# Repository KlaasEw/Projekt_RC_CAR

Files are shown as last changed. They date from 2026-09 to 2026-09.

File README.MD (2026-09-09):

# Projekt RC-Auto mit Notbremsassistent

## Inhaltsverzeichnis

1. [Projektziel](#1-projektziel)
2. [Systemüberblick](#2-systemüberblick)
3. [Hardware](#3-hardware)
4. [Notbremsassistent](#4-notbremsassistent)
5. [Telemetrie](#5-telemetrie)
6. [Software](#6-software)
7. [Stand, Grenzen, Ausblick](#7-stand-grenzen-ausblick)

---

## 1. Projektziel

Ziel des Projektes ist es, einen Notbremsassistenten für ein RC-Auto zu entwickeln. Daraus ergeben sich folgende Teilziele:

1. Das RC-Auto wird über eine Funkfernsteuerung gesteuert.
2. Das Fahrzeug soll über Abstandssensoren Hindernisse in der Umgebung erkennen.
3. Wird ein Hindernis erkannt, soll in die Ansteuerung des Motors eingegriffen werden, um das Fahrzeug zu verlangsamen und eine Kollision zu vermeiden.
4. Zur Überwachung des Fahrzeugs ist eine Übertragung der Telemetriedaten auf einen Mac zu realisieren. Die Daten sollen dort übersichtlich in einem Dashboard dargestellt werden.
5. Im Rahmen des Projektes ist zu evaluieren, welcher Mikrocontroller und welche Sensoren auf dem Fahrzeug für diesen Zweck genutzt werden können.

---

## 2. Systemüberblick

Das System umfasst das RC-Auto, einen zweiten ESP32 als Brücke zum Rechner und ein Dashboard auf dem Mac. Die Funkfernsteuerung bleibt die primäre Bedienung des Fahrzeugs. Der Mikrocontroller auf dem Auto wird zwischen den FlySky-Empfänger sowie ESC und Servo geschaltet. Die Steuerbefehle liegen am Empfänger als iBUS-Signal an. Der ESP32 wertet sie aus und gibt PWM-Signale an Motorregler und Lenkservo weiter.

Blockschaltbild des Gesamtsystems. Links Funkfernsteuerung und FlySky-Empfänger, in der Mitte der fahrzeugseitige ESP32 mit Anschlüssen zu ESC, Servo, RPLidar C1, MPU6050 und BME280. Rechts ESP-NOW zum zweiten ESP32,USB-Verbindung und Dashboard auf dem Mac. Steuerpfad und Telemetriepfad farblich tr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

Zur Erkennung von Hindernissen ist ein RPLidar C1 auf dem Fahrzeug montiert. Erkennt die Firmware ein Objekt in Fahrtrichtung, wird in die Gasvorgabe eingegriffen und das Fahrzeug verlangsamt. Über einen Schalter an der Fernsteuerung kann dieser Eingriff ein- und ausgeschaltet werden. Ein MPU6050 und ein BME280 erfassen zusätzlich Bewegungs- und Umgebungsdaten. Diese Werte dienen der Überwachung und werden mit der Telemetrie übertragen, sie fließen jedoch nicht in die Notbremslogik ein.

Zur Überwachung wird eine Telemetrieverbindung aufgebaut. Die am Fahrzeug anfallenden Daten werden per ESP-NOW an den zweiten ESP32 gesendet. Dieser ist per USB mit dem Mac verbunden und gibt die Pakete über die serielle Schnittstelle aus. Das Dashboard stellt die Telemetrie live dar.

---

## 3. Hardware

Nachfolgend wird die im Projekt verwendete Hardware beschrieben.

### 3.1 Fahrzeug und Antrieb

Foto des aufgebauten Fahrzeugs (Mali Racing BigHammer 2) von schräg vorn, sodass Antrieb, Empfängerbereich und aufgesetzte Sensorik erkennbar sind.

### 3.2 Stückliste

| Komponente | Typ |
| --- | --- |
| Auto | Mali Racing BigHammer 2 |
| Motor | QweenHobby 3670-2650KV |
| ESC | Hobbywing QuicRun WP 10BL120 G2 120A |
| Servo | B7018 9kg |
| Empfänger | FlySky FS-iA6B |
| Steuerung | FlySky FS-i6X |
| Akku | Conrad Energy 3S 25C (1800 mAh, 11,1 V) |
| Mikrocontroller | 2× ESP32 NodeMCU (Fahrzeug und Empfänger) |
| Umfeldsensor | Slamtec RPLidar C1 |
| IMU | MPU6050 (Beschleunigung und Gyroskop) |
| Umweltsensor | BME280 (Druck, Temperatur, Luftfeuchte) |
| Zubehör | Logic-Level-Shifter |
| | TS7805 (Spannungsregler 5 V) |

### 3.3 Schaltplan und Verdrahtung

Das Fahrzeug ist gemäß dem Schaltplan aufgebaut. Der Schaltplan wird in KiCad gezeichnet. Die folgende Belegung entspricht der Firmware und ist die Vorgabe für den Plan.

| Signal | ESP32 | Gegenstelle | Hinweis |
| --- | --- | --- | --- |
| Lidar RX | GPIO 16 | RPLidar TX | UART2, 460800 8N1 |
| Lidar TX | GPIO 17 | RPLidar RX | UART2 |
| iBUS RX | GPIO 34 | FlySky FS-iA6B iBUS | nur Eingang, 115200 8N1 |
| Motor PWM | GPIO 33 | ESC Signal | 50 Hz, 1000–2000 µs |
| Servo PWM | GPIO 32 | Lenkservo | 50 Hz, 1000–2000 µs |
| SDA | GPIO 21 | MPU6050, BME280 | I²C 400 kHz |
| SCL | GPIO 22 | MPU6050, BME280 | gemeinsam mit SDA |
| Lidar-Versorgung | TS7805 5 V  | RPLidar VCC | UART-Pegel 3,3 V, nicht 5 V |
| ESP32-Logik | 3,3 V | MPU, BME, UART | ESP32-Pins sind nicht 5-V-tolerant |
| Masse | GND | alle Baugruppen | gemeinsame Masse mit Akku/ESC |

Der RPLidar C1 braucht 5 V Versorgung, die UART-Leitungen sind 3,3 V. Ein Level-Shifter ist auf den Datenleitungen nur nötig, wenn 5-V-Pegel anliegen; gegenüber dem ESP32 dürfen keine 5 V auf RX/TX oder iBUS liegen. GPIO 34 kann ausschließlich lesen, deshalb liegt iBUS nur dort als Empfang. ESC und Servo werten das 3,3-V-PWM des ESP32 in der Regel direkt.

> **Abbildung 3 (Platzhalter):** KiCad-Schaltplan mit Spannungsversorgung (3S-Akku, TS7805), ESP32, iBUS, ESC, Servo, Lidar (UART) sowie I²C (MPU6050, BME280).

Foto der Verdrahtung im Fahrzeug, ergänzend zum Schaltplan.

### 3.4 Auswahl Mikrocontroller (ESP32 vs. Arduino Nano)

Zunächst wurde dieses Projekt mit einem Arduino Nano begonnen. Dieser stieß relativ schnell an seine Grenzen, da unter anderem drei native UARTs (iBUS, Lidar, Debug-Ausgabe) benötigt wurden. Daher wurde als Alternative der ESP32 getestet. Dieser verfügt zudem über die Funktechnik ESP-NOW, die für die Übertragung der Telemetriedaten sehr hilfreich war. Dadurch konnte auf den Einsatz eines zusätzlichen Funkmoduls verzichtet werden. Aus diesen Gründen wurde der Arduino Nano durch den ESP32 ersetzt.

| Kriterium | Arduino Nano | ESP32 |
| --- | --- | --- |
| Native UARTs | 1 | 3 (iBUS, Lidar, Debug-Ausgabe) |
| Funk (ESP-NOW) | nicht vorhanden | integriert |
| Zusätzliches Funkmodul | erforderlich | nicht erforderlich |

### 3.5 Auswahl Abstandssensor (RPLidar C1 vs. VL53L0X)

Im Laufe des Projektes wurde zunächst eine Kombination aus drei VL53L0X-Abstandssensoren getestet, da diese aus wirtschaftlichen Gründen zu bevorzugen war. Dabei wurden drei dieser Sensoren an der Front des Fahrzeugs über ein 3D-Druckteil montiert. Ein Sensor war direkt nach vorne ausgerichtet, die beiden anderen mit je 15° Neigung nach rechts und links. Im Rahmen der Evaluation wurde jedoch festgestellt, dass die Reichweite, in der Objekte sicher erkannt werden, maximal 1 m beträgt. Für die Geschwindigkeit, mit der sich das Fahrzeug bewegt, ist dieser Abstand deutlich zu gering.

Foto der drei VL53L0X-Sensoren am 3D-Druckteil, Frontansicht mit erkennbarer 15°-Neigung nach links und rechts.

Als Alternative wurde ein RPLidar C1 evaluiert. Der Sensor erstellt einen 360°-Scan der Umgebung mit einer Messreichweite von maximal 12 m. Die Datenmenge, die dieser Sensor liefert, ist für einen Mikrocontroller sehr hoch, daher werden nur drei Frontsektoren (links 315–345°, Mitte 345–15°, rechts 15–45°) genutzt.

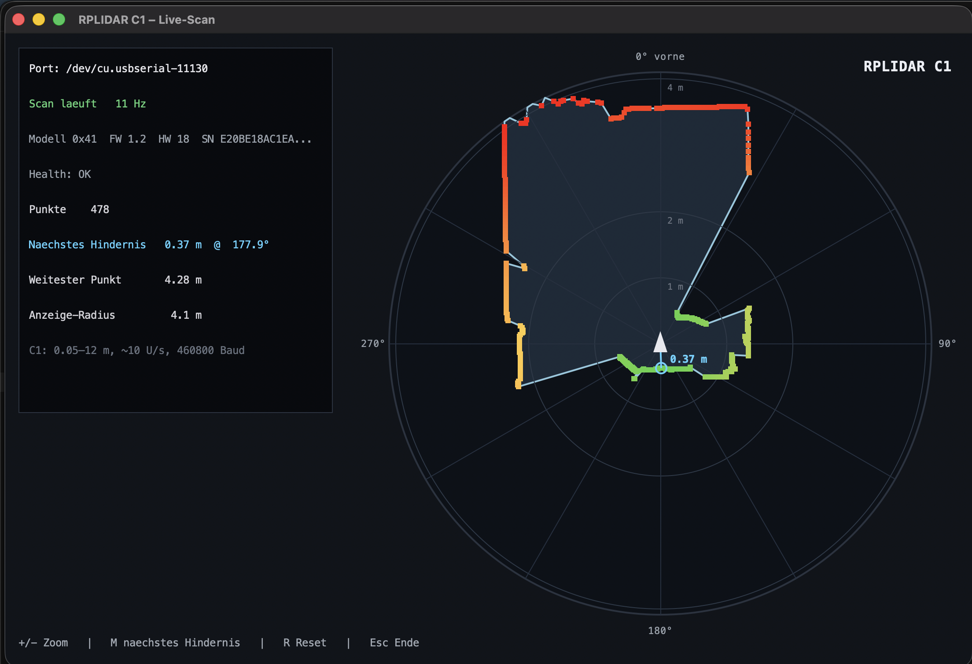
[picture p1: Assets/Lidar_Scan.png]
360° Scan des RP Lidar mir max. 12m Reichweite.


Aufgrund der gesammelten Daten wurde der Einsatz des RPLidar C1 beschlossen.

---

## 4. Notbremsassistent

Der Notbremsassistent sitzt in der Firmware des fahrzeugseitigen ESP32. Die Funkfernsteuerung bleibt die primäre Vorgabe. Der Assistent begrenzt lediglich die Gaswerte, die an den ESC weitergegeben werden. Die Lenkung wird unverändert durchgereicht.

Über einen Schalter an der Fernsteuerung (iBUS-Kanal 5) kann zwischen zwei Betriebsarten gewechselt werden. Ist der Assistent ausgeschaltet, werden die Empfängerwerte unverändert an ESC und Servo gegeben. Ist er eingeschaltet, wird die Gasvorgabe anhand der Lidar-Daten begrenzt.

Der RPLidar C1 liefert einen 360°-Scan. Für die Assistenz werden nur drei Frontsektoren ausgewertet (links 315–345°, Mitte 345–15°, rechts 15–45°). Je Sektor zählt die kleinste gültige Distanz in Millimetern. Daraus entsteht eine Gefahrenstufe. Welche Stufe tatsächlich greift, hängt von der Lenkung ab: Innerhalb einer Totzone von ±15° gilt der mittlere Sektor, außerhalb der Totzone der Sektor in Lenkrichtung.

Draufsicht der drei Frontsektoren und Zuordnung zur Lenkung. Cyan markiert den wirksamen Sektor (Totzone ±15°). Die Füllfarben im linken Beispiel entsprechen den Gefahrenstufen.

| Stufe | Bedeutung | Abstand | Begrenzung der Gasvorgabe |
| ----- | --- | --- | --- |
| 0 | frei | größer als 5000 mm  | ±60 |
| 1 | Hinweis | 3000–5000 mm | ±40 |
| 2 | Warnung | 1000–3000 mm | ±20 |
| 3 | Stopp | kleiner als 1000 mm | +10 / −15 |

Stufenkennlinie Abstand gegen Gasvorgabe

Die Gasvorgabe liegt im Bereich −100 bis 100. Auch bei freier Strecke bleibt eine Obergrenze von ±60 bestehen, solange der Assistent eingeschaltet ist. Stufe 3 ist kein vollständiger Halt: Es verbleibt ein geringer Vorwärts- und Rückwärtsanteil, damit das Fahrzeug nicht unkontrolliert stehen bleibt und weiterhin rangiert werden kann. Die Abstandsschwellen sind ein erster Arbeitspunkt und können später an das Fahrverhalten angepasst werden.

Fällt der Lidar aus oder liefert keinen gültigen Scan, wird die Gasvorgabe vorsorglich auf +15 / −20 begrenzt. Bleibt das iBUS-Signal länger als 100 ms aus, gilt Failsafe: Das Gas wird auf 0 gesetzt, die letzte Lenkstellung bleibt erhalten.

---

## 5. Telemetrie

Ziel der Telemetrie ist es, den Zustand des Fahrzeugs auf dem Mac nachvollziehbar zu machen. Dazu gehören die Vorgabe der Fernsteuerung, die tatsächlich ausgegebenen Stellgrößen, die Lidar-Sektoren samt Gefahrenstufen sowie die Messwerte von MPU6050 und BME280.

Die Übertragung erfolgt in zwei Schritten. Auf dem Fahrzeug werden die Daten in einem fest gepackten Binärpaket (Version 1, 63 Byte) zusammengestellt und per ESP-NOW an den zweiten ESP32 gesendet. Dieser prüft Länge, Versionsnummer und ein festes Erkennungsbyte am Paketanfang. Gültige Pakete werden in eine CSV-Zeile mit dem Prefix `TEL` umgewandelt und über USB (115200 8N1) an den Mac ausgegeben. Das Dashboard stellt diese Zeilen live dar und kann sie aufzeichnen.

**Abbildung 9:** Datenfluss der Telemetrie vom Fahrzeug zum Dashboard.

```mermaid
flowchart TB
    src["Sensoren und iBUS"]
    pack["Binärpaket<br/>63 Byte, Magic 0xA5"]
    now["ESP-NOW"]
    chk["Prüfung Empfänger-ESP32<br/>Länge, Version, Magic"]
    csv["CSV-Zeile<br/>Prefix TEL"]
    usb["USB 115200 8N1"]
    dash["Dashboard"]

    src -->|"Messwerte und rx"| pack
    pack -->|"binär"| now
    now --> chk
    chk -->|"gültig"| csv
    csv --> usb
    usb --> dash
```

Es werden bewusst nicht alle Lidar-Punkte übertragen. Eine vollständige Punktewolke würde das ESP-NOW-Limit von 250 Byte überschreiten. Stattdessen gehen nur die drei Sektorminima und die zugehörigen Gefahrenstufen ins Paket. Die Felder `rx` beschreiben den Wunsch der Fernsteuerung, die Felder `cmd` das, was Motor und Servo wirklich erhalten. Dadurch sind Eingriffe des Assistenten im Dashboard erkennbar. Eine laufende Sequenznummer und die Fahrzeugzeit in Millisekunden erlauben es, Verluste und die zeitliche Abfolge zu erkennen.

Die Pakete werden etwa alle 20 ms erzeugt. Der Lidar liefert neue Sektorwerte nur mit seiner Umlaufzeit; dazwischen werden die letzten gültigen Distanzen gehalten. Ungültige Sensorwerte werden auf 0 gesetzt und über Flags gekennzeichnet, unter anderem für MPU, BME, Lidar, Failsafe und einen aktiven Eingriff des Assistenten. Die Akkuspannung ist im Datenformat vorgesehen, im aktuellen Stand aber noch nicht angebunden. Die genaue Feldliste des Pakets ist in [`Note.md`](Note.md) beschrieben.

---

## 6. Software

Die einzelnen zu entwickelnden Funktionen wurden im Rahmen von diversen Prototypen getestet und am Ende zu einem gemeinsamen Stand für Fahrzeug und Empfänger zusammengeführt. Die Prototypen liegen im Ordner `prototyps/` und behandeln unter anderem iBUS, ESP-NOW, den MPU6050 und die Lidar-Auswertung. Die integrierte Software gliedert sich in drei Teile.

### 6.1 Firmware Fahrzeug

Die Firmware des Fahrzeugs liegt im Ordner `firmware_RC_Car` und wird mit PlatformIO für den ESP32 im Arduino-Framework gebaut. Sie vereint die zuvor getrennt erprobten Funktionen in einem Programm: das Auslesen des iBUS-Signals, die Ansteuerung von ESC und Servo per PWM, die Auswertung des RPLidar C1, das Einlesen von MPU6050 und BME280 sowie das Versenden der Telemetrie per ESP-NOW.

Die Lidar-Auswertung läuft in einem eigenen FreeRTOS-Task (`lidarTask`), nicht in der Arduino-`loop()`. Der Task ist auf Kern 1 gepinnt. Beim ESP32 mit Arduino-Framework läuft `loop()` standardmäßig ebenfalls auf Kern 1; Kern 0 bedient den WLAN-/ESP-NOW-Stack. Hauptschleife und Lidar-Task teilen sich damit denselben Kern. Der Lidar-Task hat die höhere Priorität (3 gegenüber 1) und gibt mit `vTaskDelay` regelmäßig ab, damit iBUS, PWM und Telemetrie weiterlaufen. Eine echte Verteilung auf zwei Anwendungskerne wäre erst gegeben, wenn der Lidar-Task auf Kern 0 läge.

In der Hauptschleife wird etwa alle 20 ms das iBUS-Signal ausgewertet, die Assistenzlogik angewendet und ein Telemetriepaket erzeugt. Parallel dazu schreibt die Firmware dieselbe CSV-Zeile auf die serielle Debug-Schnittstelle. Die Logik des Notbremsassistenten ist in Kapitel 4 beschrieben.

Vereinfachtes Firmware-Schema. Hauptschleife und Lidar-Task; beide auf Kern 1, Kern 0 für WLAN/ESP-NOW.

### 6.2 Firmware Empfänger

Die Empfänger-Firmware liegt im Ordner `firmware_Reciver`. Sie enthält keine Fahrlogik. Ihre einzige Aufgabe ist es, ESP-NOW-Pakete entgegenzunehmen, auf Länge, Versionsnummer und Erkennungsbyte zu prüfen und gültige Datensätze als CSV-Zeile über USB auszugeben. Ungültige oder unvollständige Pakete werden verworfen. Dadurch bleibt der Mac von der binären Funkstrecke entkoppelt; das Dashboard spricht nur die serielle Schnittstelle an.

### 6.3 Dashboard

Das Dashboard ist eine Python-Anwendung auf Basis von PySide6 und liegt im Ordner `Dashboard`. Es liest die CSV-Zeilen vom Empfänger-ESP32 und stellt den Fahrzeugzustand live dar. Eine Draufsicht zeigt das Auto mit Lenkeinschlag und den drei Lidar-Sektoren in der Farbe der jeweiligen Gefahrenstufe. Daneben wird die Lage im Raum aus den IMU-Daten angenähert. Werte von Fernsteuerung und Assistent (`rx` gegenüber `cmd`) sowie Flags für Sensorausfall, Failsafe und Eingriffe erscheinen in einer Seitenleiste.

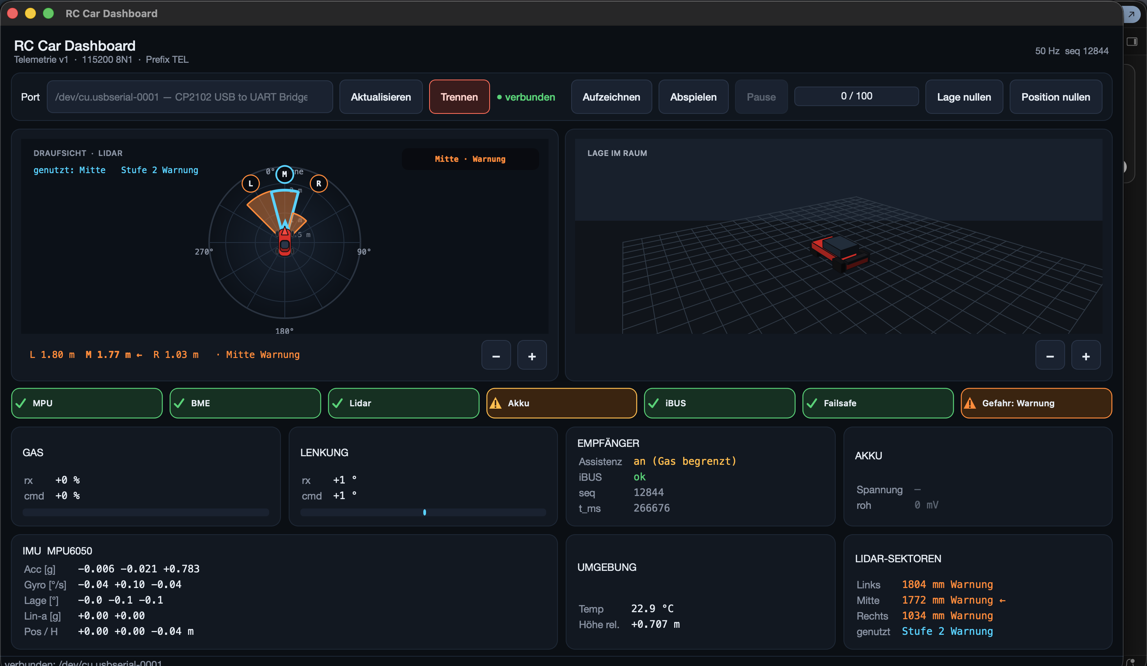
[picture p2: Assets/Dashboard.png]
Screenshot des Dashboards mit Draufsicht, Lage im Raum, Flags und Wertepanel ( / ).


Die Gefahrenstufen werden nicht neu berechnet, sondern unverändert aus dem Telemetriepaket übernommen. Zusätzlich können Live-Daten als CSV aufgezeichnet und später mit dem ursprünglichen Zeitverlauf abgespielt werden. Start und Bedienung sind in [`Dashboard/README.md`](Dashboard/README.md) beschrieben.

*Hinweis: Das Dashboard wurde vollständig über KI-Agenten erstellt.*

---

## 7. Stand, Grenzen, Ausblick

### 7.1 Stand

Die in Kapitel 1 genannten Teilziele sind im Wesentlichen umgesetzt. Das RC-Auto wird über die vorhandene Funkfernsteuerung gefahren. Der ESP32 sitzt zwischen Empfänger, ESC und Servo. Hindernisse werden mit dem RPLidar C1 in drei Frontsektoren erkannt, die Gasvorgabe kann stufenweise begrenzt und der Assistent an der Fernsteuerung ein- und ausgeschaltet werden. Mikrocontroller und Abstandssensor wurden evaluiert und begründet ausgewählt. Die Telemetrie erreicht den Mac, das Dashboard stellt die Werte live dar und kann Fahrten aufzeichnen.

### 7.2 Grenzen

Die entscheidende Grenze liegt in der Art des Eingriffs. Es wird nur die Gasvorgabe an den ESC verändert, nicht die tatsächliche Geschwindigkeit. Wird das Gas reduziert, bremst das Fahrzeug nicht unmittelbar ab, sondern rollt mit der vorhandenen kinetischen Energie weiter. Stufe 3 ist zudem kein Halt, und die Abstandsschwellen sind noch nicht an den realen Anhalteweg angepasst. Auf dieser Grundlage können Kollisionen derzeit nicht zuverlässig verhindert werden. Weitere Einschränkungen folgen daraus: Seitliche und hintere Bereiche des Lidar-Scans fließen nicht in die Assistenz ein, und die Akkuspannung ist im Datenformat vorgesehen, aber noch nicht gemessen.

### 7.3 Ausblick

Ein nächster Schritt wäre, die Fahrgeschwindigkeit zu messen und die Ansteuerung über einen PID-Regelkreis zu führen. Die Gefahrenstufe würde dann eine Zielgeschwindigkeit vorgeben, nicht nur eine Drosselung des Sticks. Erst damit ließe sich das Fahrzeug nach einer Reduktion wirklich verzögern, statt es ausrollen zu lassen. Ergänzend sollten die Abstandsschwellen am Fahrzeug kalibriert und die Akkuspannung in die Telemetrie übernommen werden.

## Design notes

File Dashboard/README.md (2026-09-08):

# RC Car Dashboard

Live-Telemetrie vom Empfänger-ESP32 über USB-Serial. Dunkles PySide6-Dashboard auf dem Mac: Draufsicht mit Lidar-Sektoren, Lage im Raum, Werte, Flag-Warnungen, CSV-Aufzeichnung und Wiedergabe.

Datenpfad: Auto-ESP → ESP-Now → Empfänger-ESP (`firmware_Reciver`) → USB 115200 8N1 → diese App. Protokoll laut `Note.md` (CSV-Zeilen mit Prefix `TEL`).

## Start

Python 3.9 oder neuer. Im Ordner `Dashboard/`:

```bash
python3 -m venv .venv
source .venv/bin/activate
python3 -m pip install -r requirements.txt
python3 main.py
```

## Verbinden

1. Empfänger-ESP32 per USB anschließen.
2. **PlatformIO-Serial-Monitor, Arduino-IDE und andere Programme schließen.** Der Port darf nur einmal geöffnet sein.
3. Im Dashboard den Port wählen (auf macOS `/dev/cu.…`, nicht `/dev/tty.…`) und **Verbinden**.
4. Baudrate ist fest **115200**. Debug-Zeilen ohne `TEL` werden ignoriert.

Ports aktualisieren, falls der Stick später eingesteckt wird.

## Bedienung

| Aktion | Wirkung |
| --- | --- |
| Verbinden / Trennen | Serial öffnen oder schließen |
| Aufzeichnen | Live-Pakete nach `recordings/tel_YYYYMMDD_HHMMSS.csv` |
| Abspielen | vorhandene CSV mit Original-Timing über `t_ms` |
| Pause | Wiedergabe anhalten |
| Lage nullen / `R` | Roll, Pitch, Yaw auf aktuelle Lage setzen |
| Position nullen / Leertaste | Spur und Position zurücksetzen |
| `X` / `Y` / `Z` | IMU-Achse invertieren |

## Anzeige

- **Draufsicht:** Auto von oben, Vorderräder nach `cmd_servo`. Weicht `rx_servo` ab, erscheint ein gelber Wunsch-Pfeil. Drei Lidar-Sektoren (Links 315–345°, Mitte 345–15°, Rechts 15–45°), Farbe nach Gefahrenstufe. Der von der Firmware genutzte Sektor (`rx_servo`-Deadzone 15°) ist cyan umrandet. `+` / `−` oder Mausrad zoomen.
- **Lage im Raum:** Komplementärfilter und Bewegung wie im Prototyp `Visualisierung_Car_Movment`. Ebenfalls `+` / `−` zum Zoomen.
- **Empfänger / Assistenz:** Fernsteuer-Schalter (iBUS-Kanal 5). *an* = Notbremsassistent aktiv (Lidar begrenzt Gas), *aus* = Werte werden durchgereicht.
- **Flags:** Warn-Dreieck, sobald der ungünstige Zustand vorliegt (MPU/BME/Lidar/Akku ungültig, Failsafe, iBUS stale). Gefahr folgt `danger_used`: Hinweis, Warnung oder Stop.
- **Werte:** `rx` vs. `cmd`, IMU, Temperatur, relative Höhe, Akkuspannung in Volt, Lidar mm.

Gefahrenstufen und `danger_used` kommen aus dem Paket, sie werden nicht neu berechnet.

## Aufnahmen

Ordner: `Dashboard/recordings/`. Erste Zeile ist der Header (`version,seq,t_ms,…`), danach dieselben Spalten wie die TEL-Zeile ohne Prefix. Live-`TEL,…`-Dumps können ebenfalls abgespielt werden. Nicht-TEL-Zeilen werden übersprungen.

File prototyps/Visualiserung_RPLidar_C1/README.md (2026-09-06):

# RPLIDAR C1 am Mac anschließen und visualisieren

Schritt-für-Schritt: Sensor per USB mit dem Mac verbinden und die Live-Punktewolke mit `visualize_lidar.py` anzeigen.

## Was du brauchst

- Slamtec **RPLIDAR C1**
- Das mitgelieferte **USB-Adapterboard** (meist CP210x, USB-A oder USB-C)
- Das kurze **XH2.54-Kabel** zwischen Lidar und Adapter (oft schon steckt)
- Einen freien USB-Anschluss am Mac (bei USB-C-Macs ggf. USB-A-Adapter)
- Python 3.9 oder neuer (`python3 --version`)

Der C1 braucht **5 V** und etwa **230 mA**. Ein normaler Mac-USB-Port reicht. Ungepowerte USB-Hubs lieber vermeiden.

Der Sensor ist Laserklasse 1. Trotzdem nicht direkt in das optische Fenster starren und das Fenster nicht abdecken.

---

## 1. Hardware verbinden

1. Lege den C1 auf eine **ebene, freie Fläche**. Der Markierungsstrich bzw. das Kabel am Sockel zeigt nach vorne (0° im Radar).
2. Stecke das **5-polige Kabel** vom Lidar in das USB-Adapterboard. Die Stecker sind verpolungssicher – nicht mit Gewalt umdrehen.
3. Verbinde das Adapterboard **per USB mit dem Mac**.
4. Der Motor darf sich jetzt noch nicht drehen. Die Laser-Einheit startet erst, wenn das Skript den Scan-Befehl schickt.

Pinbelegung nur zur Kontrolle (falls du ohne Adapterboard misst):

| Signal | Richtung | Bemerkung |
| --- | --- | --- |
| VCC | Versorgung | **5 V**, nicht 3,3 V |
| TX | Lidar → Mac | UART-Daten |
| RX | Mac → Lidar | UART-Befehle |
| GND | Masse | gemeinsam |

Logikpegel der UART-Leitungen: 3,3 V. Versorgung trotzdem 5 V.

---

## 2. Prüfen, ob macOS den Adapter sieht

Ab macOS 11 (Big Sur) ist der **CP210x-Treiber von Apple** schon dabei. Einen extra SiLabs-Treiber brauchst du in der Regel nicht. Einen alten, selbst installierten SiLabs-Treiber besser entfernen – der kann mit dem Apple-Treiber kollidieren.

Terminal öffnen und **alle** `cu`-Geräte listen (zsh-tauglich, ohne Glob-Fehler):

```bash
ls /dev/cu.*
```

Relevant sind Einträge mit `usbserial`, `SLAB`, `wchusbserial` oder `usbmodem`. Gezielter:

```bash
ls /dev/cu.* | grep -iE 'usbserial|SLAB|wchusb|usbmodem'
```

Erwartetes Ergebnis, zum Beispiel:

```text
/dev/cu.usbserial-1130
```

Nicht verwenden: `ls /dev/cu.usbserial* /dev/cu.SLAB* /dev/cu.wchusbserial*`. In zsh bricht der Befehl ab, sobald **eines** der Muster nichts findet – auch wenn der Lidar schon als `usbserial-…` da ist.

Wichtig: Immer **`/dev/cu.*`** verwenden, nicht `/dev/tty.*`. Die `tty.*`-Geräte warten auf ein Modem-Signal und blockieren.

Wenn nichts erscheint:

1. Anderen USB-Anschluss bzw. anderen Adapter versuchen.
2. Systemeinstellungen → Allgemein → Info → Systembericht → USB: nach „CP210x“, „Silicon Labs“ oder „USB-Serial“ suchen.
3. Kabel und Adapterboard prüfen. Manche Boards brauchen erst den Lidar-Stecker, bevor sie am USB enumerieren.
4. Falls wirklich kein Treiber da ist: [CP210x VCP Driver von Silicon Labs](https://www.silabs.com/developers/usb-to-uart-bridge-vcp-drivers).

---

## 3. Python-Umgebung einrichten

Im Projektordner:

```bash
cd prototyps/RPLidar_C1
python3 -m venv .venv
source .venv/bin/activate
python3 -m pip install -r requirements.txt
```

Es wird nur **pyserial** benötigt. Die Grafik läuft mit Tkinter, das bei der macOS-Python-Installation schon dabei ist.

Falls `tkinter` fehlt (selten, z. B. bei manchen Homebrew-Pythons):

```bash
brew install python-tk
```

---

## 4. Visualisierung starten

Zuerst die Ports listen:

```bash
python3 visualize_lidar.py --list
```

Der Eintrag mit `*` ist der vermutete C1 (CP210x / usbserial). Wenn gleichzeitig ein ESP32 steckt, den C1-Port explizit angeben.

Dann starten:

```bash
python3 visualize_lidar.py
```

oder fest:

```bash
python3 visualize_lidar.py --port /dev/cu.usbserial-1130
```

Nach 1–2 Sekunden sollte sich der Kopf drehen und im Fenster ein Radar erscheinen: Sensor in der Mitte, 0° oben = vorne.

### Bedienung

| Taste / Geste | Wirkung |
| --- | --- |
| `+` / `-` oder Mausrad | Zoom (Anzeige-Radius) |
| `M` | Nächstes Hindernis ein/aus |
| `R` | Zoom auf 8 m zurück |
| `Esc` oder `Q` | Beenden, Motor stoppen |

### Nützliche Optionen

```bash
python3 visualize_lidar.py --range 4      # Innenraum, 4 m Radius
python3 visualize_lidar.py --baud 460800  # Standard des C1, nur ändern wenn nötig
```

---

## 5. Wenn etwas nicht klappt

**Fenster bleibt gelb bei „verbinde / Motor hochfahren“**

- Port mit `--list` prüfen und `--port` setzen.
- Arduino-IDE, PlatformIO-Serial-Monitor und andere Programme schließen. Der Port darf nur einmal geöffnet sein.
- USB kurz ziehen und wieder einstecken, dann Skript neu starten.

**Fehler „Keine Antwort vom Lidar“**

- Baudrate muss **460800** sein (nicht 115200 wie beim A1).
- Kabel TX/RX nicht vertauscht (beim Original-Adapterboard kein Thema).
- Nach einem harten Abbruch 2 Sekunden warten: Der C1 braucht nach einem Reset etwas Zeit.

**Motor dreht nicht**

- 5-V-Versorgung über USB prüfen (kein passiver Hub).
- Skript beendet den Motor sauber. Nach Absturz USB kurz trennen.

**Punktewolke verdreht**

- Sensor so drehen, dass Kabel/Markierung nach vorne zeigt. 0° ist die Blickrichtung nach vorne.

**„Resource busy“ / Permission denied**

- Anderen Prozess vom Port nehmen: `lsof /dev/cu.usbserial-*`
- Nicht `/dev/tty.usbserial-*` verwenden.

**Schutzstopp**

- Optisches Fenster frei? Sensor nicht festgeklemmt?
- USB trennen, ein paar Sekunden warten, wieder einstecken.

---

## Kurzüberblick C1

| Parameter | Wert |
| --- | --- |
| Reichweite | 0,05–12 m (weiß)  |
| Scanfrequenz | typisch 10 Hz |
| Winkelauflösung | ca. 0,72° |
| Schnittstelle | UART 8N1 |
| Baudrate | **460800** |
| Versorgung | 5 V / ~230 mA |

Das Skript spricht das Slamtec-Protokoll direkt (STOP, RESET, GET_INFO, GET_HEALTH, SCAN). Die bekannten Python-Pakete `rplidar` / `pyrplidar` sind für den C1 oft unzuverlässig (Hardware-Handshake `dsrdtr` blockiert den Datenstrom).

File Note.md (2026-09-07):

# Mac Adressen

ESP_32_Auto:    1C:C3:AB:BC:05:10
ESP_32_Reciver: 1C:C3:AB:BC:17:28

# Telemetrie-Datenformat v1

Pfad: Auto-ESP → ESP-Now → Empfänger-ESP → USB-Serial → Visualisierung.

Zwei Darstellungen, gleicher Inhalt:

- **ESP-Now:** gepacktes Binärstruct (`__attribute__((packed))`), Little-Endian, fest unter 250 Byte.
- **USB zum Rechner:** eine CSV-Zeile pro Paket, Prefix `TEL`.

Magic `0xA5`, Version `1`. Felder nur hinten anhängen; Version hochzählen.

`magic` ist ein festes Erkennungsbyte am Paketanfang. Der Empfänger prüft zuerst: erstes Byte `0xA5`? Sonst kein Telemetriepaket (Rauschen, falscher Sender, abgeschnittene Daten). `0xA5` = `10100101`, bewusst ungewöhnlich, damit es selten zufällig passt. Entspricht dem Prefix `TEL` in der CSV-Zeile.

## Sektoren und Gefahrenstufen

Lidar-Sektoren (0° = vorne, je 30°), Index in Arrays:

| Index | Name | Winkel |
| ----- | --- | --- |
| 0 | Links  | 315°–345° |
| 1 | Mitte  | 345°–15°  |
| 2 | Rechts | 15°–45° |

Entfernung: kleinste gültige Distanz im Sektor, **mm**. `0` = kein Echo / ungültig.

Gefahrenstufe je Sektor (`danger[i]`), Abstandsschwellen grob zum Start (später kalibrieren):

| Stufe | Bedeutung | Distanz (Richtwert) |
| ----- | --- | --- |
| 0 | frei | > 4000 mm |
| 1 | Hinweis | 2000–4000 mm |
| 2 | Warnung | 1000–2000 mm |
| 3 | Stopp | < 1000 mm |

`danger_used` = Stufe, die **aktuell** Gas/Lenkung begrenzt (typisch Maximum der relevanten Sektoren, nicht nur Anzeige).

## ESP-Now Struct

Sender und Empfänger müssen byteidentisch sein. Keine `int`/`bool` (plattformabhängig).

```c
typedef struct __attribute__((packed)) {
  uint8_t  magic;          // 0xA5
  uint8_t  version;        // 1
  uint16_t seq;            // laufende Nummer, Wrap bei 65535
  uint32_t t_ms;           // millis() im Auto

  // Empfänger (iBUS, gemappt wie im IBUS-Prototyp)
  int16_t  rx_gas;         // -100 … 100
  int16_t  rx_servo;       // -45 … 45 (links +, rechts −)
  uint8_t  rx_control;     // 0 = begrenzt, 1 = voll
  uint8_t  rx_ok;          // 1 = frisches iBUS-Frame (< 100 ms)

  // Ansteuerung nach Failsafe / Gefahrenlogik
  int16_t  cmd_gas;        // -100 … 100
  int16_t  cmd_servo;      // -45 … 45

  // MPU6050
  float    ax, ay, az;     // g
  float    gx, gy, gz;     // °/s, gyro-kalibriert
  float    temp_c;         // °C (BME280, Fallback MPU)

  // BME280
  float    alt_rel_m;      // m relativ zur Kalibrierhöhe

  // Akku
  uint16_t vbat_mv;        // mV, 0 = ungültig

  // Lidar + Gefahr
  uint16_t lidar_mm[3];    // L / M / R, 0 = ungültig
  uint8_t  danger[3];      // L / M / R, 0…3
  uint8_t  danger_used;    // 0…3, aktiv verwendete Stufe

  uint8_t  flags;          // siehe unten
} TelemetryV1;
```

Größe: **63 Byte**. ESP-Now-Limit: 250 Byte.

`flags` Bitmaske:

| Bit | Bedeutung |
| --- | --- |
| 0 | MPU gültig |
| 1 | BME gültig |
| 2 | Lidar-Scan gültig |
| 3 | Failsafe aktiv (kein iBUS) |
| 4 | Gefahr greift ein (`cmd` ≠ `rx`) |
| 5 | Akkuspannung gültig |

Ungültige Sensorwerte auf `0` setzen und das zugehörige Flag löschen. Nicht senden, wenn `magic`/`version` nicht passen oder `len != sizeof(TelemetryV1)`.

## Serial-CSV (Empfänger → PC)

Eine Zeile, 115200 8N1, kein Leerzeichen:

```
TEL,<ver>,<seq>,<t_ms>,<rx_gas>,<rx_servo>,<rx_control>,<rx_ok>,<cmd_gas>,<cmd_servo>,<ax>,<ay>,<az>,<gx>,<gy>,<gz>,<temp_c>,<alt_rel_m>,<vbat_mv>,<lidar_l>,<lidar_c>,<lidar_r>,<d_l>,<d_c>,<d_r>,<d_used>,<flags>
```

Floats mit 3 Nachkommastellen. Ganzzahlen ungeändert. Debug-Zeilen ohne Prefix `TEL` ignoriert die Visualisierung.

Beispiel:

```
TEL,1,42,123456,-20,8,1,1,-10,8,0.012,-0.980,0.040,1.20,-0.30,0.05,24.6,0.120,11840,1850,920,2400,1,2,0,2,39
```

## Hinweise für die Pipeline

- Cadence: ca. **20–50 ms** (20–50 Hz). Lidar-Umlauf ~10 Hz: Sektorwerte bis zum nächsten Scan halten.
- `seq` und `t_ms` zum Erkennen von Verlust und Schätzen der Latenz.
- `rx_*` = Wunsch der Fernsteuerung, `cmd_*` = was Motor/Servo wirklich bekommen. So sieht die Visualisierung Eingriffe.
- Keine volle Lidar-Punktewolke über ESP-Now (zu groß). Nur die drei Sektor-Minima.
- `vbat_mv` in Millivolt (z. B. `11840` = 11,840 V). `0` plus Flag-Bit 5 gelöscht, wenn die Messung fehlt.
- Optional später (Struct hinten anhängen, Version 2): VL53L0X `tof_mm[3]`, ESP-Now-RSSI nur lokal am Empfänger (steht nicht im Auto-Paket).

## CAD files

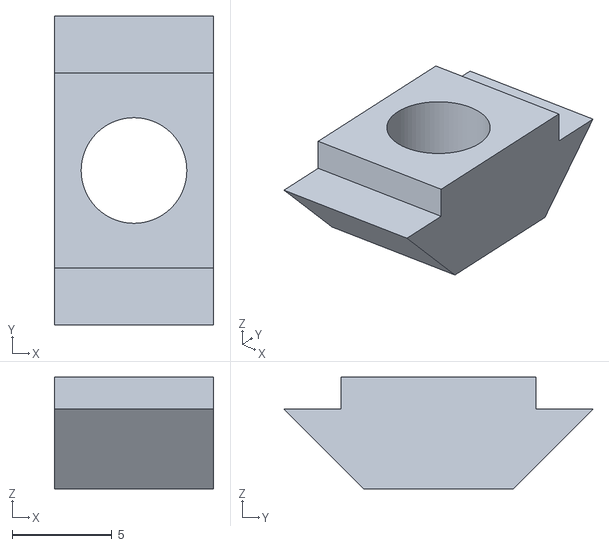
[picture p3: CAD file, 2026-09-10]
Hardware(3D)/Halterung Breadboard/Halterung Konterplatte.stl
8.00 x 15.5 x 5.60

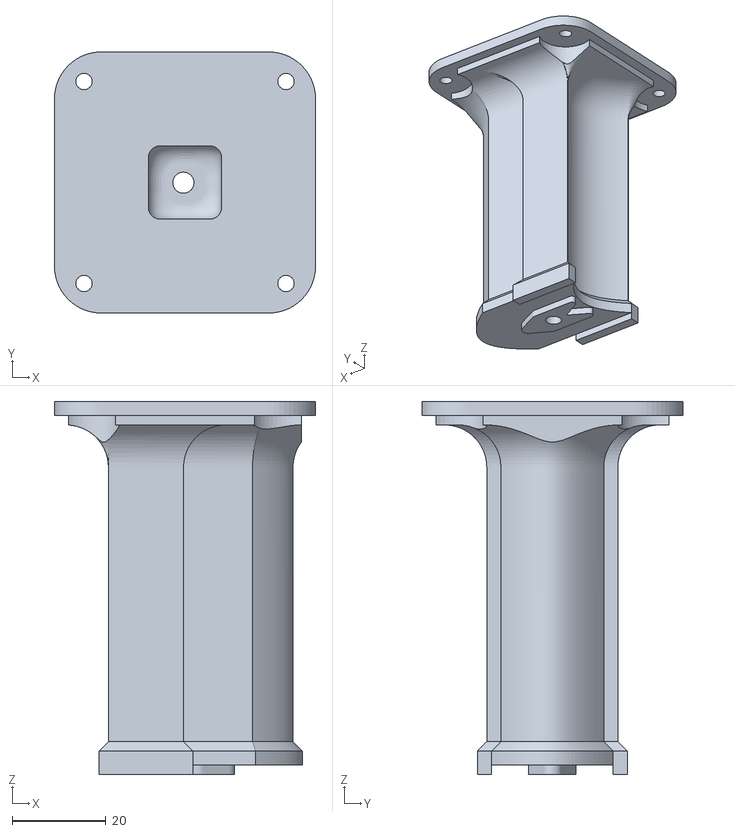
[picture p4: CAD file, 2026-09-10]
Hardware(3D)/Halterung Lidar/Halterung RP Lidar.stl
55.6 x 55.6 x 79.4

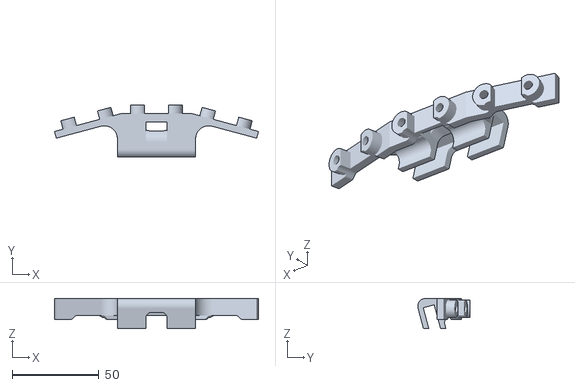
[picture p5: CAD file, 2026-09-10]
Hardware(3D)/Halterung VL53L0X/Sensor Halterung.stl
117.3 x 30.2 x 17.4

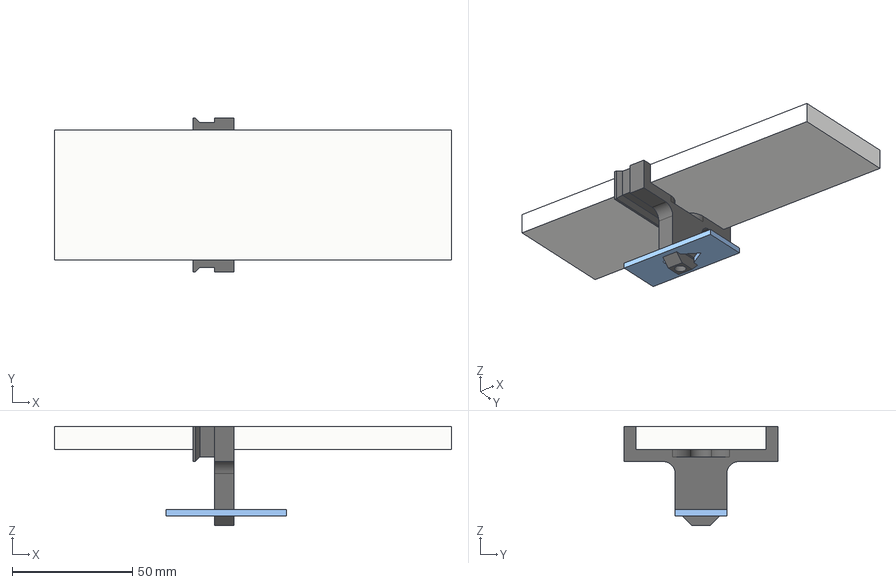
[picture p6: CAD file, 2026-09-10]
Hardware(3D)/Halterung Breadboard/Halterung Breadboard.step
165.0 x 64.2 x 41.2 mm
Breadborad
Auto Befestigungspunkt
Breadboard_Halterung
Halterung Konterplatte

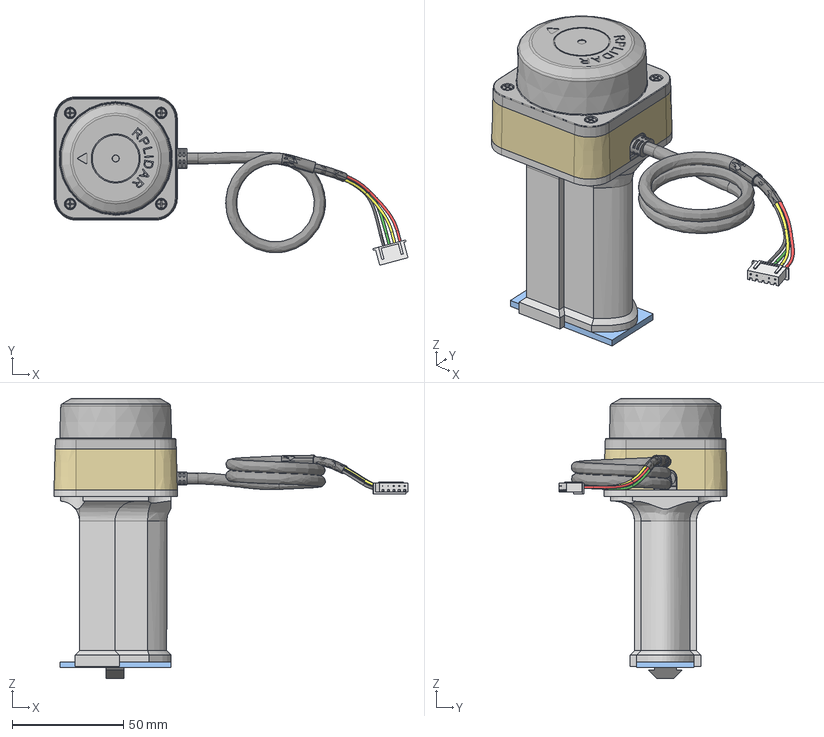
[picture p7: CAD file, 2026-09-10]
Hardware(3D)/Halterung Lidar/Halterung RP Lidar C1.step
159.5 x 75.9 x 126.3 mm
Auto Befestigungspunkt
Halterung
davi0C08CA42kk0b
Halterung Konterplatte

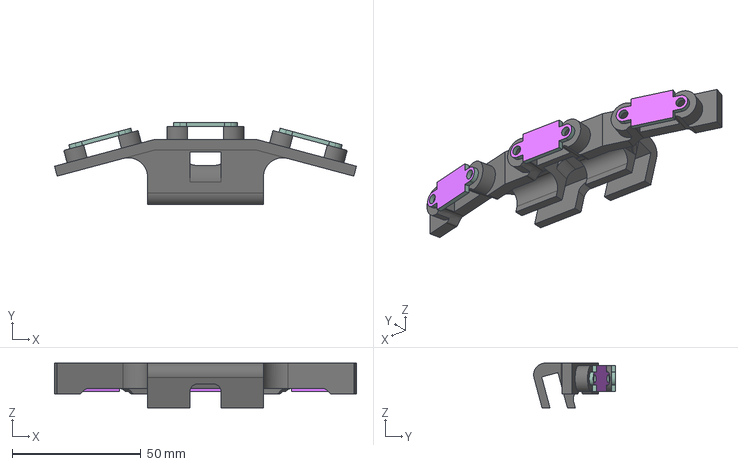
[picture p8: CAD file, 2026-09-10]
Hardware(3D)/Halterung VL53L0X/Halterung ToF Sensor.step
117.3 x 31.8 x 17.4 mm
Sensor Halterung
Sensor x 3

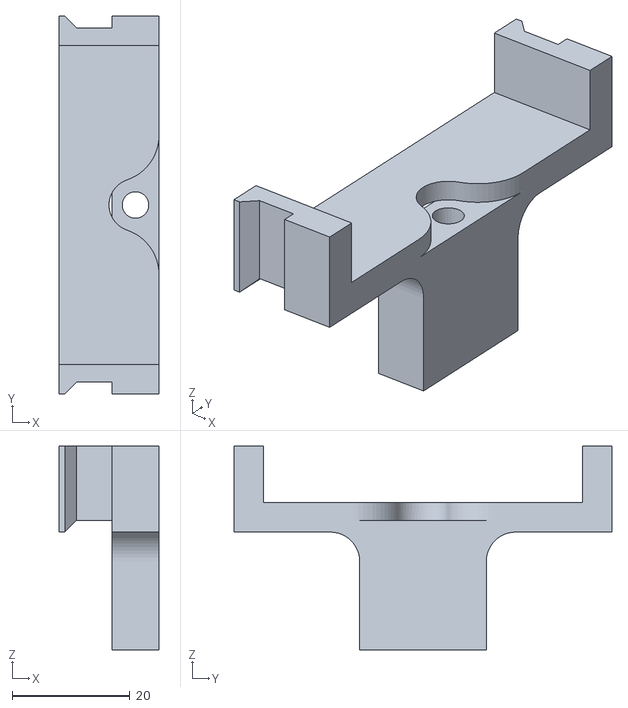
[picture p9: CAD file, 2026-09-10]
Hardware(3D)/Halterung Breadboard/Breadboard_Halterung.stl
17.0 x 64.2 x 34.6

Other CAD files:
Hardware(3D)/Halterung Breadboard/Halterung Breadboard.f3d
Hardware(3D)/Halterung VL53L0X/Sensor Halterung.f3d

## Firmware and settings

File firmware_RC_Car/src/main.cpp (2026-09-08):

/*
Autor: Klaas Ewald
Version: 1.0
Datum: 12.09.2026
Zielsetzung: Notbremsassistent für ein RC-Auto

Der Mikrocontroller wird zwischen Receiver sowie ESC und Servo geschaltet.
Im ersten Fahrmodus werden die Empfängerwerte unverändert durchgereicht.
Im zweiten Fahrmodus wird die Ansteuerung basierend auf Sensorergebnissen
beeinflusst. Ziel ist es, eine Kollision des Autos mit anderen Objekten
zu verhindern. Dazu wird die Umgebung mit dem Lidar-Sensor gescannt.
Wird ein Hindernis erkannt, soll die Geschwindigkeit reduziert und im
Zweifelsfall das Fahrzeug gestoppt werden.

Zusätzlich sollen über ESP-NOW Telemetriedaten, die am Fahrzeug gemessen
wurden, an einen zweiten ESP übertragen werden. Dieser ESP dient als
Brücke zu einem auf dem PC laufenden Visualisierungsdashboard.
Die Kommunikation zwischen dem zweiten ESP und dem PC erfolgt über die
serielle Schnittstelle.

Hardware:
Auto:            Mali Racing BigHammer 2
Motor:           QweenHobby 3670-2650KV
ESC:             Hobbywing QuicRun WP 10BL120 G2 120A
Servo:           B7018 9kg
Receiver:        FlySky FS-iA6B
Steuerung:       FlySky FS-i6X
Akku:            Conrad Energy 3S 25C (1800 mAh, 11,1 V)
Mikrocontroller: ESP32 NodeMCU
Sensoren:        BME280 (Druck, Temperatur, Luftfeuchte)
                 MPU6050 (Beschleunigung und Gyroskop)
                 Slamtec RPLidar C1
Zubehör:         Logic-Level-Shifter
                 TS7805 (Spannungsregler 5 V)


======================================================================================================*/


//Bibliotheken
//======================================================================================================
#include <Arduino.h>
#include <ESP32Servo.h>
#include <cstring>
#include <cmath>
#include <esp_now.h>
#include <WiFi.h>
#include <Wire.h>
#include <Adafruit_MPU6050.h>
#include <Adafruit_Sensor.h>
#include <Adafruit_BME280.h>
#include <cstdio>

//Variablen
//======================================================================================================

//Variablen RPLidar C1
const int LIDAR_RX_PIN = 16;
const int LIDAR_TX_PIN = 17;

float minDistLeft = 99999.0;
float minDistCenter = 99999.0;
float minDistRight = 99999.0;

const float MIN_VALID_DISTANCE = 100.0;  // mm, 0 = kein Echo
const int16_t STEER_DEADZONE = 15;       // Grad, darunter gilt Geradeaus

byte paket[5];
int paketIndex = 0;
bool lidarReady = false;
unsigned long lastLidarScanMs = 0;
unsigned long lastLidarByteMs = 0;
unsigned long lastLidarRestartMs = 0;
uint8_t lidarFailCount = 0;
unsigned long lastTelMs = 0;

struct LidarShare {
  uint16_t mm[3];
  uint8_t danger[3];
  uint8_t valid;
};
volatile LidarShare lidarShare = {};

//Variablen MPU6050 & BME280
static const int I2C_SDA_PIN = 21;
static const int I2C_SCL_PIN = 22;
static const float ALT_FILTER = 0.35f;

Adafruit_MPU6050 mpu;
Adafruit_BME280 bme;
bool mpuReady = false;
bool bmeReady = false;

float gyroOffsetX = 0;
float gyroOffsetY = 0;
float gyroOffsetZ = 0;
float pressureBaselinePa = 101325.0f;
float altFiltered = 0;

//Variablen ESP Now
uint8_t receiverAddress[] = {0x1C, 0xC3, 0xAB, 0xBC, 0x17, 0x28};

esp_now_peer_info_t peerInfo;
bool espNowReady = false;

//Variablen IBUS
const int IBUS_RX_PIN = 34;
const int MOTOR_PIN = 33;
const int SERVO_PIN = 32;

const int PWM_MIN_US = 1000;
const int PWM_NEUTRAL_US = 1500;
const int PWM_MAX_US = 2000;

Servo motor;
Servo steering;

const int IBUS_PACKET_SIZE = 32;
const unsigned long IBUS_STALE_MS = 100;

// 0-basiert: CH1=0 ... CH14=13
const int IBUS_CH_GAS = 1;
const int IBUS_CH_SERVO = 3;
const int IBUS_CH_CONTROL = 4;

uint8_t ibusBuf[IBUS_PACKET_SIZE];
int ibusIndex = 0;
uint16_t ibusChannels[14];
bool ibusValid = false;
unsigned long ibusLastMs = 0;

//Variablen Telemetrie Struct
const uint8_t TEL_MAGIC = 0xA5;
const uint8_t TEL_VERSION = 1;

const uint8_t FLAG_MPU = (1 << 0);
const uint8_t FLAG_BME = (1 << 1);
const uint8_t FLAG_LIDAR = (1 << 2);
const uint8_t FLAG_FAILSAFE = (1 << 3);
const uint8_t FLAG_DANGER = (1 << 4);
const uint8_t FLAG_VBAT = (1 << 5);

typedef struct __attribute__((packed)) {
  uint8_t  magic;
  uint8_t  version;
  uint16_t seq;
  uint32_t t_ms;

  int16_t  rx_gas;
  int16_t  rx_servo;
  uint8_t  rx_control;
  uint8_t  rx_ok;

  int16_t  cmd_gas;
  int16_t  cmd_servo;

  float    ax, ay, az;
  float    gx, gy, gz;
  float    temp_c;

  float    alt_rel_m;

  uint16_t vbat_mv;

  uint16_t lidar_mm[3];
  uint8_t  danger[3];
  uint8_t  danger_used;

  uint8_t  flags;
} TelemetryV1;

static_assert(sizeof(TelemetryV1) == 63, "TelemetryV1 muss 63 Byte sein");

TelemetryV1 tel;

//Prototypen
//======================================================================================================

int mapGas(int pulseUs);
int mapServo(int pulseUs);
int mapControl(int pulseUs);
void writeMotor(int gas);
void writeSteering(int servo);
bool ibusChecksumOk();
void parseIbus();
void initTelemetry();
void fillRxFromIbus();
void computeCmd();
void applyCmd();
bool readMpu(TelemetryV1 &data);
float relativeAltitude(float pressurePa);
void readBme(TelemetryV1 &data);
void calibrateGyro();
void calibrateAltitude();
bool initBme();
void processLidarPoint(float angle, float distance, bool isNewScan);
void parseLidar();
void lidarTask(void *pv);
void applyLidarToTel();
void lidarBefehl(byte cmd);
void lidarBefehlWert(byte cmd, uint16_t wert);
bool warteAufAntwort(unsigned long timeoutMs);
void lidarFullReset();
bool lidarStartScan(unsigned long timeoutMs);
void recoverLidar();
uint16_t sectorToMm(float minDist);
uint8_t dangerFromMm(uint16_t mm);
void publishLidarScan();
void finishLidarScan();
void clearLidarTelemetry();
void updateDangerUsed();
void serialDebug();

//Setup
//======================================================================================================

void setup() {
  //Initialisierung der Seriellen Schnittstelle
  Serial.begin(115200);
  Serial.println("Start ESP_32");

  //Initialisierung der Telemetrie
  initTelemetry();

  //Initialisierung der Motoren und Servos
  motor.setPeriodHertz(50);
  steering.setPeriodHertz(50);
  motor.attach(MOTOR_PIN, PWM_MIN_US, PWM_MAX_US);
  steering.attach(SERVO_PIN, PWM_MIN_US, PWM_MAX_US);
  motor.writeMicroseconds(PWM_NEUTRAL_US);
  steering.writeMicroseconds(PWM_NEUTRAL_US);

  //Initialisierung der IBUS Schnittstelle
  Serial1.setRxBufferSize(1024);
  Serial1.begin(115200, SERIAL_8N1, IBUS_RX_PIN, -1);

  //Initialisierung WiFi-Modul
  WiFi.mode(WIFI_STA);
  Serial.print("Eigene MAC: ");
  Serial.println(WiFi.macAddress());

  if (esp_now_init() != ESP_OK) {
    Serial.println("Fehler: ESP-NOW Init fehlgeschlagen");
  } else {
    memcpy(peerInfo.peer_addr, receiverAddress, 6);
    peerInfo.channel = 0;
    peerInfo.encrypt = false;
    if (esp_now_add_peer(&peerInfo) != ESP_OK) {
      Serial.println("Fehler: Peer konnte nicht hinzugefuegt werden");
    } else {
      espNowReady = true;
      Serial.println("ESP-NOW bereit");
    }
  }

  //Initialisierung des I2C-Interface
  Wire.begin(I2C_SDA_PIN, I2C_SCL_PIN);
  Wire.setClock(400000);
  delay(50);

  //Initialisierung des MPU6050
  if (!mpu.begin(MPU6050_I2CADDR_DEFAULT, &Wire)) {
    Serial.println("Fehler: MPU6050 Init fehlgeschlagen");
  } else {
    mpuReady = true;
    mpu.setAccelerometerRange(MPU6050_RANGE_2_G);
    mpu.setGyroRange(MPU6050_RANGE_250_DEG);
    mpu.setFilterBandwidth(MPU6050_BAND_44_HZ);
    calibrateGyro();
    Serial.println("MPU6050 bereit");
  }

  //Initialisierung des BME280
  if (!initBme()) {
    Serial.println("Fehler: BME280 Init fehlgeschlagen");
  } else {
    bmeReady = true;
    calibrateAltitude();
    Serial.println("BME280 bereit");
  }

  //Initialisierung des RPLidar C1
  Serial2.setRxBufferSize(8192);
  Serial2.begin(460800, SERIAL_8N1, LIDAR_RX_PIN, LIDAR_TX_PIN);
  delay(50);

  lidarFullReset();
  if (lidarStartScan(4000)) {
    lidarReady = true;
    lastLidarScanMs = millis();
    lastLidarByteMs = millis();
    Serial.println("RPLidar bereit");
  } else {
    Serial.println("Fehler: RPLidar Init fehlgeschlagen");
  }
  xTaskCreatePinnedToCore(lidarTask, "lidar", 4096, NULL, 3, NULL, 1);

  //Ende des Setup
  Serial.println("StartUp complet");

}

//Loop
//======================================================================================================

void loop() {
  parseIbus();

  if (millis() - lastTelMs < 20) {
    return;
  }
  lastTelMs = millis();

  fillRxFromIbus();
  applyLidarToTel();

  computeCmd();
  applyCmd();

  //Auslesen MPU6050
  if (mpuReady) {
    readMpu(tel);
  }

  //Auslesen BME280
  if (bmeReady) {
    readBme(tel);
  } else {
    tel.alt_rel_m = 0;
    tel.flags &= ~FLAG_BME;
    if (!(tel.flags & FLAG_MPU)) {
      tel.temp_c = 0;
    }
  }

  //Serial Ausgabe für Debugging
  serialDebug();

  //ESP-NOW Senden
  if (espNowReady) {
    esp_err_t result = esp_now_send(receiverAddress, (uint8_t *)&tel, sizeof(tel));
    if (result != ESP_OK) {
      Serial.println("Fehler beim Senden");
    }
  }
}

//Funktionen
//======================================================================================================

int mapGas(int pulseUs) {
  return map(pulseUs, 999, 2000, -100, 100);
}

int mapServo(int pulseUs) {
  return map(pulseUs, 999, 2000, 45, -45);
}

int mapControl(int pulseUs) {
  return (pulseUs < 1500) ? 1 : 0;
}

void writeMotor(int gas) {
  motor.writeMicroseconds(constrain(map(gas, -100, 100, PWM_MIN_US, PWM_MAX_US), PWM_MIN_US, PWM_MAX_US));
}

void writeSteering(int servo) {
  steering.writeMicroseconds(constrain(map(servo, 45, -45, PWM_MIN_US, PWM_MAX_US), PWM_MIN_US, PWM_MAX_US));
}

bool ibusChecksumOk() {
  uint16_t sum = 0;
  for (int i = 0; i < 30; i++) {
    sum += ibusBuf[i];
  }
  uint16_t checksum = ibusBuf[30] | (ibusBuf[31] << 8);
  return checksum == (uint16_t)(0xFFFF - sum);
}

void parseIbus() {
  while (Serial1.available()) {
    uint8_t b = Serial1.read();

    if (ibusIndex == 0) {
      if (b != 0x20) {
        continue;
      }
      ibusBuf[ibusIndex++] = b;
      continue;
    }

    if (ibusIndex == 1 && b != 0x40) {
      ibusIndex = 0;
      if (b == 0x20) {
        ibusBuf[ibusIndex++] = b;
      }
      continue;
    }

    ibusBuf[ibusIndex++] = b;
    if (ibusIndex < IBUS_PACKET_SIZE) {
      continue;
    }

    if (ibusChecksumOk()) {
      for (int i = 0; i < 14; i++) {
        ibusChannels[i] = ibusBuf[2 + i * 2] | (ibusBuf[3 + i * 2] << 8);
      }
      ibusValid = true;
      ibusLastMs = millis();
    }
    ibusIndex = 0;
  }
}

void initTelemetry() {
  memset(&tel, 0, sizeof(tel));
  tel.magic = TEL_MAGIC;
  tel.version = TEL_VERSION;
}

void fillRxFromIbus() {
  bool ibusFresh = ibusValid && (millis() - ibusLastMs) < IBUS_STALE_MS;

  tel.t_ms = millis();
  tel.seq++;

  if (!ibusFresh) {
    tel.rx_ok = 0;
    return;
  }

  tel.rx_ok = 1;
  tel.rx_gas = (int16_t)mapGas(ibusChannels[IBUS_CH_GAS]);
  tel.rx_servo = (int16_t)mapServo(ibusChannels[IBUS_CH_SERVO]);
  tel.rx_control = (uint8_t)mapControl(ibusChannels[IBUS_CH_CONTROL]);
}

void computeCmd() {
  if (!tel.rx_ok) {
    tel.cmd_gas = 0;
    tel.flags |= FLAG_FAILSAFE;
    tel.flags &= ~FLAG_DANGER;
    return;
  }

  tel.flags &= ~FLAG_FAILSAFE;
  tel.flags &= ~FLAG_DANGER;

  int16_t gas = tel.rx_gas;
  if (tel.rx_control != 1) {
    if (!(tel.flags & FLAG_LIDAR)) { //Lidar Sensor fehlerhaft
      if (gas > 15) {
        gas = 15;
      }
      if (gas < -20) {
        gas = -20;
      }
      tel.flags |= FLAG_DANGER;
    } else if (tel.danger_used == 1) {  // Hinweis: 3000–5000 mm
      if (gas > 40) {
        gas = 40;
      }
      if (gas < -40) {
        gas = -40;
      }
    } else if (tel.danger_used == 2) {  // Warnung: 1000–3000 mm
      if (gas > 20) {
        gas = 20;
      }
      if (gas < -20) {
        gas = -20;
      }
      tel.flags |= FLAG_DANGER;
    } else if (tel.danger_used == 3) {  // Stopp: < 1000 mm
      if (gas > 10) {
        gas = 10;
      }
      if (gas < -15) {
        gas = -15;
      }
      tel.flags |= FLAG_DANGER;
    } else {  // frei: > 4000 mm 
      if (gas > 60) {
        gas = 60;
      }
      if (gas < -60) {
        gas = -60;
      }
    }
  }

  tel.cmd_gas = gas;
  tel.cmd_servo = tel.rx_servo;
}

void applyCmd() {
  writeMotor(tel.cmd_gas);
  writeSteering(tel.cmd_servo);
}

bool readMpu(TelemetryV1 &data) {
  sensors_event_t accel;
  sensors_event_t gyro;
  sensors_event_t mpuTemp;
  if (!mpu.getEvent(&accel, &gyro, &mpuTemp)) {
    data.ax = 0;
    data.ay = 0;
    data.az = 0;
    data.gx = 0;
    data.gy = 0;
    data.gz = 0;
    data.flags &= ~FLAG_MPU;
    return false;
  }

  data.ax = accel.acceleration.x / SENSORS_GRAVITY_STANDARD;
  data.ay = accel.acceleration.y / SENSORS_GRAVITY_STANDARD;
  data.az = accel.acceleration.z / SENSORS_GRAVITY_STANDARD;
  data.gx = gyro.gyro.x * RAD_TO_DEG - gyroOffsetX;
  data.gy = gyro.gyro.y * RAD_TO_DEG - gyroOffsetY;
  data.gz = gyro.gyro.z * RAD_TO_DEG - gyroOffsetZ;
  data.temp_c = mpuTemp.temperature;
  data.flags |= FLAG_MPU;
  return true;
}

float relativeAltitude(float pressurePa) {
  if (pressureBaselinePa < 1.0f) {
    return 0;
  }
  return 44330.0f * (1.0f - pow(pressurePa / pressureBaselinePa, 0.1903f));
}

void readBme(TelemetryV1 &data) {
  float t = bme.readTemperature();
  float pressurePa = bme.readPressure();

  if (isnan(t) || pressurePa <= 10000.0f) {
    data.alt_rel_m = 0;
    data.flags &= ~FLAG_BME;
    if (!(data.flags & FLAG_MPU)) {
      data.temp_c = 0;
    }
    return;
  }

  data.temp_c = t;
  float altRaw = relativeAltitude(pressurePa);
  altFiltered += ALT_FILTER * (altRaw - altFiltered);
  data.alt_rel_m = altFiltered;
  data.flags |= FLAG_BME;
}

void calibrateGyro() {
  const int samples = 200;
  float sumX = 0;
  float sumY = 0;
  float sumZ = 0;
  int ok = 0;

  for (int i = 0; i < samples; i++) {
    if (!readMpu(tel)) {
      delay(10);
      continue;
    }
    sumX += tel.gx;
    sumY += tel.gy;
    sumZ += tel.gz;
    ok++;
    delay(10);
  }

  if (ok == 0) {
    return;
  }

  gyroOffsetX = sumX / ok;
  gyroOffsetY = sumY / ok;
  gyroOffsetZ = sumZ / ok;
}

void calibrateAltitude() {
  const int samples = 40;
  float sumP = 0;
  int ok = 0;
  for (int i = 0; i < samples; i++) {
    float p = bme.readPressure();
    if (p > 10000.0f) {
      sumP += p;
      ok++;
    }
    delay(25);
  }
  if (ok > 0) {
    pressureBaselinePa = sumP / ok;
  }
  altFiltered = 0;
}

bool initBme() {
  if (bme.begin(0x76, &Wire) || bme.begin(0x77, &Wire)) {
    bme.setSampling(
        Adafruit_BME280::MODE_NORMAL,
        Adafruit_BME280::SAMPLING_X1,
        Adafruit_BME280::SAMPLING_X16,
        Adafruit_BME280::SAMPLING_NONE,
        Adafruit_BME280::FILTER_X16,
        Adafruit_BME280::STANDBY_MS_0_5);
    return true;
  }
  return false;
}

//Lidar Task (FreeRTOS Task)
void lidarTask(void *pv) {
  (void)pv;
  for (;;) {
    parseLidar();
    vTaskDelay(1);
  }
}

void applyLidarToTel() {
  tel.lidar_mm[0] = lidarShare.mm[0];
  tel.lidar_mm[1] = lidarShare.mm[1];
  tel.lidar_mm[2] = lidarShare.mm[2];
  tel.danger[0] = lidarShare.danger[0];
  tel.danger[1] = lidarShare.danger[1];
  tel.danger[2] = lidarShare.danger[2];
  if (lidarShare.valid) {
    tel.flags |= FLAG_LIDAR;
  } else {
    tel.flags &= ~FLAG_LIDAR;
  }
  updateDangerUsed();
}

void parseLidar() {
  if (!lidarReady) {
    clearLidarTelemetry();
    recoverLidar();
    return;
  }

  int processed = 0;
  while (Serial2.available()) {
    lastLidarByteMs = millis();
    paket[paketIndex] = Serial2.read();
    paketIndex++;

    if (paketIndex < 5) continue;

    int startBit = paket[0] & 0x01;
    int startBitInv = (paket[0] >> 1) & 0x01;
    int checkBit = paket[1] & 0x01;

    if (startBit == startBitInv || checkBit != 1) {
      for (int i = 0; i < 4; i++) paket[i] = paket[i + 1];
      paketIndex = 4;
      if (++processed >= 256) {
        break;
      }
      continue;
    }

    float winkel = ((paket[1] >> 1) | (paket[2] << 7)) / 64.0;
    if (winkel >= 360.0) winkel = winkel - 360.0;
    float distanz = (paket[3] | (paket[4] << 8)) / 4.0;

    paketIndex = 0;
    processLidarPoint(winkel, distanz, startBit == 1);
    if (++processed >= 256) {
      break;
    }
  }

  unsigned long now = millis();
  if (lastLidarByteMs != 0 && (now - lastLidarByteMs) > 300) {
    while (Serial2.available()) {
      Serial2.read();
    }
    paketIndex = 0;
    minDistLeft = 99999.0;
    minDistCenter = 99999.0;
    minDistRight = 99999.0;
    clearLidarTelemetry();
    recoverLidar();
    return;
  }

  if (lastLidarScanMs != 0 && (now - lastLidarScanMs) >= 180) {
    finishLidarScan();
  }
}

void processLidarPoint(float angle, float distance, bool isNewScan) {
  if (isNewScan) {
    unsigned long now = millis();
    if (now - lastLidarScanMs >= 80) {
      finishLidarScan();
    }
  }

  if (distance < MIN_VALID_DISTANCE) return;
  if (distance > 12000.0) return;

  // 0° = vorne (Kabel/Markierung). Je Zone 30°.
  // Links: 315-345°   Mitte: 345-15°   Rechts: 15-45°
  if (angle >= 315.0 && angle < 345.0) {
    if (distance < minDistLeft) minDistLeft = distance;
  } else if (angle >= 345.0 || angle < 15.0) {
    if (distance < minDistCenter) minDistCenter = distance;
  } else if (angle >= 15.0 && angle < 45.0) {
    if (distance < minDistRight) minDistRight = distance;
  }
}

uint16_t sectorToMm(float minDist) {
  if (minDist >= 99999.0f) {
    return 0;
  }
  return (uint16_t)minDist;
}

uint8_t dangerFromMm(uint16_t mm) {
  if (mm == 0) {
    return 0;
  }
  if (mm < 1000) {
    return 3;
  }
  if (mm < 3000) {
    return 2;
  }
  if (mm <= 5000) {
    return 1;
  }
  return 0;
}

void publishLidarScan() {
  lidarShare.mm[0] = sectorToMm(minDistLeft);
  lidarShare.mm[1] = sectorToMm(minDistCenter);
  lidarShare.mm[2] = sectorToMm(minDistRight);
  lidarShare.danger[0] = dangerFromMm(lidarShare.mm[0]);
  lidarShare.danger[1] = dangerFromMm(lidarShare.mm[1]);
  lidarShare.danger[2] = dangerFromMm(lidarShare.mm[2]);
  lidarShare.valid = 1;
}

void finishLidarScan() {
  bool scanHatDaten = (minDistLeft < 99999.0f) ||
                     (minDistCenter < 99999.0f) ||
                     (minDistRight < 99999.0f);
  if (scanHatDaten) {
    publishLidarScan();
  }
  minDistLeft = 99999.0;
  minDistCenter = 99999.0;
  minDistRight = 99999.0;
  lastLidarScanMs = millis();
}

void clearLidarTelemetry() {
  lidarShare.mm[0] = 0;
  lidarShare.mm[1] = 0;
  lidarShare.mm[2] = 0;
  lidarShare.danger[0] = 0;
  lidarShare.danger[1] = 0;
  lidarShare.danger[2] = 0;
  lidarShare.valid = 0;
}

void updateDangerUsed() {
  if (!(tel.flags & FLAG_LIDAR)) {
    tel.danger_used = 0;
    return;
  }

  // rx_servo: links +, rechts −
  if (tel.rx_servo > STEER_DEADZONE) {
    tel.danger_used = tel.danger[2];
  } else if (tel.rx_servo < -STEER_DEADZONE) {
    tel.danger_used = tel.danger[0];
  } else {
    tel.danger_used = tel.danger[1];
  }
}

void lidarFullReset() {
  lidarBefehl(0x25);
  delay(50);
  lidarBefehl(0x40);
  delay(2000);
  while (Serial2.available()) {
    Serial2.read();
  }
  lidarBefehlWert(0xA8, 600);
  lidarBefehlWert(0xF0, 660);
  delay(1200);
  while (Serial2.available()) {
    Serial2.read();
  }
}

bool lidarStartScan(unsigned long timeoutMs) {
  while (Serial2.available()) {
    Serial2.read();
  }
  paketIndex = 0;
  lidarBefehl(0x20);
  return warteAufAntwort(timeoutMs);
}

void recoverLidar() {
  unsigned long now = millis();
  if (lastLidarRestartMs != 0 && (now - lastLidarRestartMs) < 2500) {
    return;
  }
  lastLidarRestartMs = now;
  lidarFailCount++;

  if (lidarFailCount >= 3) {
    lidarFullReset();
    lidarFailCount = 0;
  } else {
    lidarBefehl(0x25);
    delay(50);
    while (Serial2.available()) {
      Serial2.read();
    }
  }

  if (lidarStartScan(1500)) {
    lidarReady = true;
    lastLidarByteMs = millis();
    lastLidarScanMs = millis();
    lidarFailCount = 0;
  } else {
    lidarReady = false;
  }
}

void lidarBefehl(byte cmd) {
  Serial2.write(0xA5);
  Serial2.write(cmd);
  Serial2.flush();
}

void lidarBefehlWert(byte cmd, uint16_t wert) {
  byte frame[6];
  frame[0] = 0xA5;
  frame[1] = cmd;
  frame[2] = 2;
  frame[3] = wert & 0xFF;
  frame[4] = (wert >> 8) & 0xFF;
  frame[5] = frame[0] ^ frame[1] ^ frame[2] ^ frame[3] ^ frame[4];
  Serial2.write(frame, 6);
  Serial2.flush();
}

bool warteAufAntwort(unsigned long timeoutMs) {
  unsigned long start = millis();
  int vorher = 0;

  while (millis() - start < timeoutMs) {
    if (!Serial2.available()) {
      delay(1);
      continue;
    }

    int b = Serial2.read();
    if (vorher == 0xA5 && b == 0x5A) {
      for (int i = 0; i < 5; i++) {
        unsigned long waitStart = millis();
        while (!Serial2.available()) {
          if (millis() - waitStart > timeoutMs) return false;
        }
        Serial2.read();
      }
      return true;
    }
    vorher = b;
  }
  return false;
}

void serialDebug() {
  char line[256];
  snprintf(
      line, sizeof(line),
      "TEL,%u,%u,%lu,%d,%d,%u,%u,%d,%d,%.3f,%.3f,%.3f,%.3f,%.3f,%.3f,%.3f,%.3f,%u,%u,%u,%u,%u,%u,%u,%u,%u\n",
      (unsigned)tel.version,
      (unsigned)tel.seq,
      (unsigned long)tel.t_ms,
      (int)tel.rx_gas,
      (int)tel.rx_servo,
      (unsigned)tel.rx_control,
      (unsigned)tel.rx_ok,
      (int)tel.cmd_gas,
      (int)tel.cmd_servo,
      tel.ax, tel.ay, tel.az,
      tel.gx, tel.gy, tel.gz,
      tel.temp_c, tel.alt_rel_m,
      (unsigned)tel.vbat_mv,
      (unsigned)tel.lidar_mm[0],
      (unsigned)tel.lidar_mm[1],
      (unsigned)tel.lidar_mm[2],
      (unsigned)tel.danger[0],
      (unsigned)tel.danger[1],
      (unsigned)tel.danger[2],
      (unsigned)tel.danger_used,
      (unsigned)tel.flags);
  Serial.print(line);
}

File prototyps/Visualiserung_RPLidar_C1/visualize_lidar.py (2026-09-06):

#!/usr/bin/env python3
"""
Live-Visualisierung des Slamtec RPLIDAR C1 am Mac (USB).

Der Sensor spricht binaer ueber UART @ 460800 Baud. Dieses Skript findet den
USB-Adapter, startet den Scan und zeichnet jeden 360-Grad-Umlauf als Radar.

  python3 visualize_lidar.py
  python3 visualize_lidar.py --port /dev/cu.usbserial-XXXX
  python3 visualize_lidar.py --list

Tasten: +/- Zoom, R Ansicht zuruecksetzen, M Min-Distanz markieren, Esc Ende.
Mausrad zoomt ebenfalls. Den Serial-Monitor anderer Programme vorher schliessen.
"""

from __future__ import annotations

import argparse
import math
import struct
import sys
import threading
import time
import tkinter as tk

try:
    import serial
    from serial.tools import list_ports
except ImportError:
    print("pyserial fehlt. Installieren mit:")
    print("  python3 -m pip install -r requirements.txt")
    sys.exit(1)


BAUD = 460800
SYNC = 0xA5
SYNC2 = 0x5A
CMD_STOP = 0x25
CMD_RESET = 0x40
CMD_SCAN = 0x20
CMD_GET_INFO = 0x50
CMD_GET_HEALTH = 0x52
CMD_MOTOR_PWM = 0xF0
CMD_MOTOR_RPM = 0xA8

MIN_RANGE_M = 0.05
MAX_RANGE_M = 12.0
DEFAULT_VIEW_M = 8.0
MOTOR_RPM = 600
MOTOR_PWM = 660

WIDTH, HEIGHT = 1100, 720
RADAR_MARGIN = 36


def dist_color(distance_m: float, view_m: float) -> str:
    """Nahe Punkte gruen, ferne rot."""
    t = max(0.0, min(1.0, distance_m / max(view_m, 0.5)))
    if t < 0.5:
        r = int(40 + 430 * t)
        g = 210
        b = 70
    else:
        u = (t - 0.5) * 2.0
        r = 255
        g = int(210 * (1.0 - u))
        b = int(70 * (1.0 - u))
    return "#%02x%02x%02x" % (min(255, r), max(0, g), max(0, b))


class ScanState:
    def __init__(self):
        self.lock = threading.Lock()
        self.points: list[tuple[float, float, int]] = []
        self.hz = 0.0
        self.point_count = 0
        self.min_dist = 0.0
        self.min_angle = 0.0
        self.max_dist = 0.0
        self.have_data = False
        self.error = ""
        self.port = ""
        self.info = ""
        self.health = ""
        self._scan_times: list[float] = []

    def set_scan(self, points: list[tuple[float, float, int]]):
        now = time.monotonic()
        valid = [
            (angle, dist, quality)
            for angle, dist, quality in points
            if MIN_RANGE_M <= dist <= MAX_RANGE_M and quality > 0
        ]
        with self.lock:
            self.points = valid
            self.point_count = len(valid)
            self.have_data = True
            self._scan_times.append(now)
            self._scan_times = [t for t in self._scan_times if now - t < 1.0]
            self.hz = float(len(self._scan_times))
            if valid:
                nearest = min(valid, key=lambda p: p[1])
                farthest = max(valid, key=lambda p: p[1])
                self.min_angle, self.min_dist = nearest[0], nearest[1]
                self.max_dist = farthest[1]
            else:
                self.min_dist = self.max_dist = self.min_angle = 0.0

    def snapshot(self):
        with self.lock:
            return (
                list(self.points),
                self.hz,
                self.point_count,
                self.min_dist,
                self.min_angle,
                self.max_dist,
                self.have_data,
                self.error,
                self.port,
                self.info,
                self.health,
            )


def find_ports():
    scored = []
    keywords = (
        "cp210",
        "slab",
        "silicon",
        "usbserial",
        "usbmodem",
        "wchusb",
        "ch340",
        "ch910",
        "uart",
        "usb-serial",
    )
    skip = ("bluetooth", "debug-console", "incoming", "soundcore", "airpod", "headset")
    usb_hints = ("usb", "serial", "slab", "cp210", "wch", "uart", "ch340", "ch910")
    for port in list_ports.comports():
        blob = f"{port.device} {port.description} {port.manufacturer or ''}".lower()
        if any(word in blob for word in skip):
            continue
        if not any(word in blob for word in usb_hints):
            continue
        score = sum(1 for key in keywords if key in blob)
        if "cp210" in blob or "silicon" in blob or "slab" in blob:
            score += 3
        if sys.platform == "darwin" and port.device.startswith("/dev/tty."):
            score -= 2
        scored.append((score, port))
    scored.sort(key=lambda item: item[0], reverse=True)
    return scored


def pick_port(explicit: str | None) -> str | None:
    if explicit:
        return explicit
    scored = find_ports()
    if not scored:
        return None
    return scored[0][1].device


def send_cmd(ser: serial.Serial, cmd: int, payload: bytes = b""):
    if payload:
        frame = bytes([SYNC, cmd, len(payload)]) + payload
        checksum = 0
        for byte in frame:
            checksum ^= byte
        ser.write(frame + bytes([checksum]))
    else:
        ser.write(bytes([SYNC, cmd]))
    ser.flush()


def read_descriptor(ser: serial.Serial, leftover: bytearray, timeout: float = 3.0):
    deadline = time.monotonic() + timeout
    while time.monotonic() < deadline:
        chunk = ser.read(ser.in_waiting or 1)
        if chunk:
            leftover.extend(chunk)
        idx = leftover.find(bytes([SYNC, SYNC2]))
        if idx >= 0 and len(leftover) >= idx + 7:
            desc = bytes(leftover[idx : idx + 7])
            del leftover[: idx + 7]
            size = desc[2] | (desc[3] << 8) | (desc[4] << 16) | ((desc[5] & 0x3F) << 24)
            return size, desc[6], leftover
        time.sleep(0.005)
    raise TimeoutError("Keine Antwort vom Lidar (Descriptor fehlt).")


def read_exact(ser: serial.Serial, leftover: bytearray, size: int, timeout: float = 2.0):
    deadline = time.monotonic() + timeout
    while len(leftover) < size:
        if time.monotonic() > deadline:
            raise TimeoutError("Unvollstaendige Antwort vom Lidar.")
        chunk = ser.read(max(1, min(ser.in_waiting or 1, size - len(leftover))))
        if chunk:
            leftover.extend(chunk)
        else:
            time.sleep(0.005)
    data = bytes(leftover[:size])
    del leftover[:size]
    return data


def parse_info(data: bytes) -> str:
    model, fw_minor, fw_major, hardware = data[0], data[1], data[2], data[3]
    serial_hex = data[4:20].hex().upper()
    return (
        f"Modell 0x{model:02X}  FW {fw_major}.{fw_minor}  "
        f"HW {hardware}  SN {serial_hex[:12]}..."
    )


def parse_health(data: bytes) -> str:
    status = data[0]
    error_code = data[1] | (data[2] << 8)
    labels = {0: "OK", 1: "Warnung", 2: "Schutzstopp"}
    text = labels.get(status, f"Status {status}")
    if error_code:
        text += f"  Code {error_code}"
    return text
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

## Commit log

2026-09-06 Prototyp Visualisierung RP Lidar C1
2026-09-07 Switch to IBUS and Servo/Motor Control
2026-09-07 Add IBUS and Motor Corntroll to Firmware
2026-09-08 Add Lidar über FreeRTOS Task
2026-09-08 Add Recoverfunction for Lidar sensor
2026-09-10 Add 3d Print Files
    [Breadboard_Halterung.stl, Halterung Breadboard.f3d, Halterung Breadboard.step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]
